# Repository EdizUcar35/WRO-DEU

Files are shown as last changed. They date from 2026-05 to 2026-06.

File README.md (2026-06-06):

# CENGOT — WRO 2026 Future Engineers

This repository contains the engineering materials for Team CENGOT's WRO 2026 entry. The project structure follows the WRO engineering-materials template and provides placeholders and guidance for the files required by the competition.

# Table of contents

- Project overview
- Repository structure
- Hardware & BOM (placeholder)
- Schematics and wiring
- 3D models and mechanical parts
- Software (control code)
- Media (photos & video)

---

# Project overview

CENGOT Robot is an autonomous small-scale vehicle developed for the WRO 2026 Future Engineers track. The platform is designed to compete in both the Open and Obstacle challenge modules by combining reliable low-level control, on-board perception, and modular mechanical design. The system emphasizes reproducibility, easy repair (3D-printable parts), and clear documentation so judges and developers can reproduce the build and test results.

## Objectives
- Reliable line-following on printed tracks with robust recovery when the line is lost.
- Color-based and distance-based obstacle detection with safe avoidance behaviours.
- Modular, printable mechanical parts for quick iteration and repair.
- Well-documented build instructions, wiring diagrams, and reproducible software deployment steps.

## System architecture
- High-level processing: Raspberry Pi (Zero 2 W or 4) running Python/OpenCV for camera-based perception, mission planning and telemetry.
- Low-level control: ESP32 for real-time motor and servo control, sensor polling, and encoder counting.
- Sensors: 
- Actuators: Two DC gear motors with encoders driven by an H-bridge motor driver; servo for steering.

## Software overview
- Perception: OpenCV-based color segmentation and contour analysis for obstacle detection.
- Control:
- Utilities: calibration scripts (camera, sensors), data-logging and replay tools, and automated upload scripts for microcontroller firmware.

## Performance targets
- Line-following accuracy: maintain center within ±2 cm at typical test speeds.
- Obstacle detection: reliably detect colored obstacles at ≥0.5 m in normal indoor lighting.
- End-to-end demo runtime: at least 3 minutes running on the chosen battery (depends on battery capacity and motor load).

## Repository deliverables
- Mechanical files and printable parts: `models/`
- Wiring diagrams and schematics: `schemes/`
- Source code and sketches: `src/`
- Team and vehicle photos: `t-photos/`, `v-photos/`
- Demonstration videos and links: `video/`

## Members:

Artun Andaç (Team Leader)

- Freshman, Dokuz Eylül University.
- Role:
- Contact: artunandac0@gmail.com

Ediz Uçar

- Freshman, Dokuz Eylül University
- Role:
- Contact: ucar.ediz35@gmail.com

Can Özdemir

- Freshman, Dokuz Eylül University
- Role:
- Contact: canozdemir8084@gmail.com

Coach:

Hakan Akduman

- Senior, Dokuz Eylül University
- Contact: hakanakduman2002@gmail.com

---

# Repository structure

| Directory | Purpose / Contents |
|---|---|
| [models/](models/) | 3D-printable parts and CAD files (3MF, STL, STEP) with assembly notes and print settings |
| [schemes/](schemes/) | Circuit diagrams, wiring lists and schematics (PNG, JPG, PDF) |
| [src/](src/) | Source code: Arduino sketches, Python scripts, utilities, and build/upload instructions |
| [other/](other/) | Additional documentation: datasheets, communication protocols, SBC setup notes, datasets, troubleshooting |
| [t-photos/](t-photos/) | Team photos (official and casual) with captions and names |
| [v-photos/](v-photos/) | Vehicle photos covering multiple views (front, back, left, right, top, bottom) |
| [video/](video/) | Demonstration videos and `video.md` with links and timestamps |

---

# Hardware 

Add links to datasheets and pinouts in `schemes/`.

---

| Used in | Name | Photo | Description | Quantity |
|---|---|---|---|---|
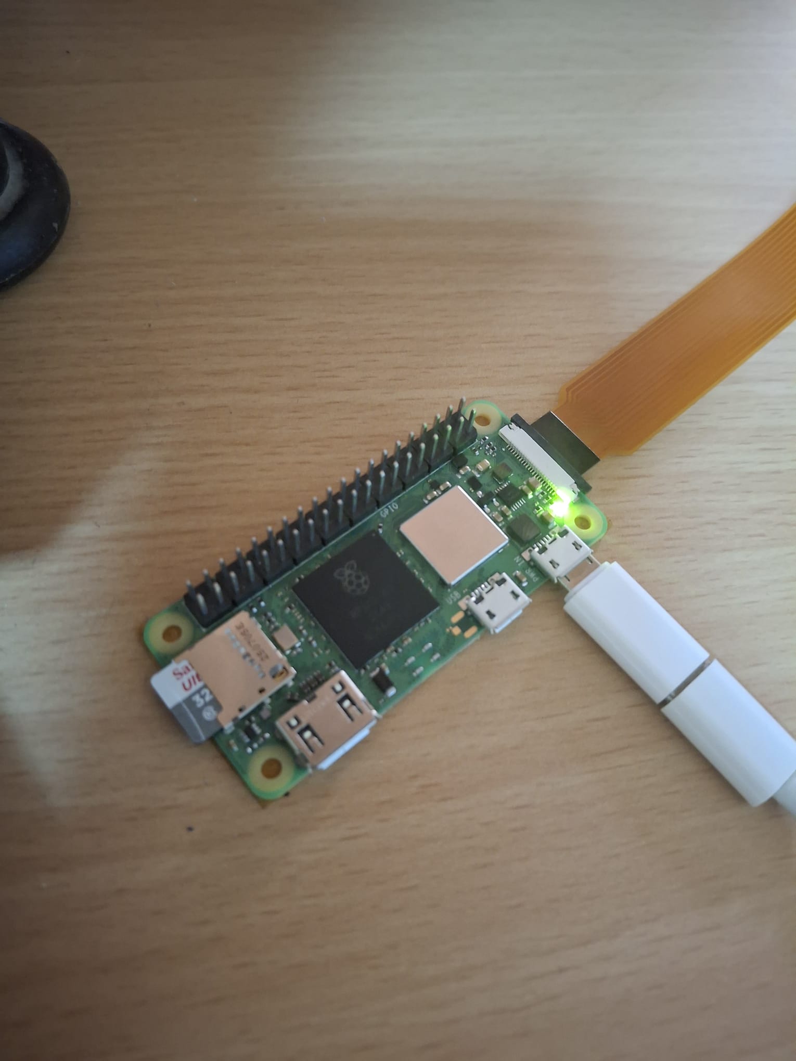
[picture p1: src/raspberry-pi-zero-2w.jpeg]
| Obstacle detecting | Raspberry Pi Zero 2 W |  | Main onboard computer that runs the Python vision software and processes camera frames with OpenCV. | 1 |
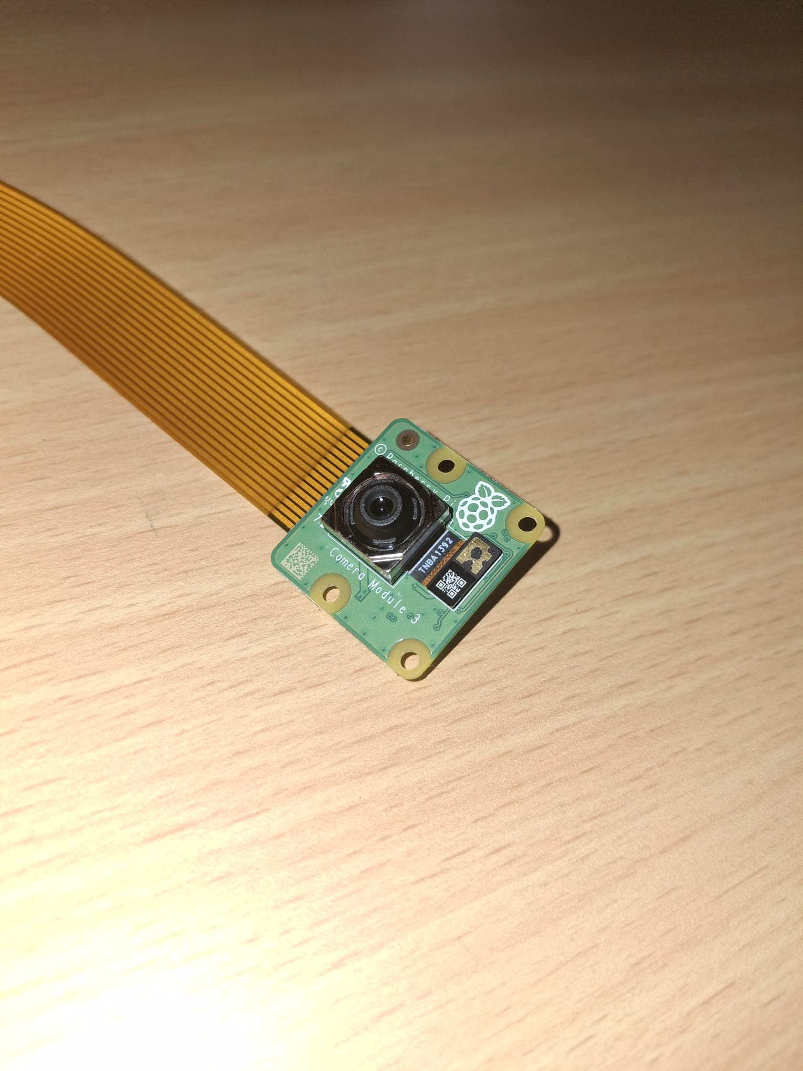
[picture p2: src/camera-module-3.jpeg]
| Obstacle detecting | Raspberry Pi Camera Module 3 |  | Camera module that captures the live image stream used to detect the red and green obstacle signs on the track. | 1 |
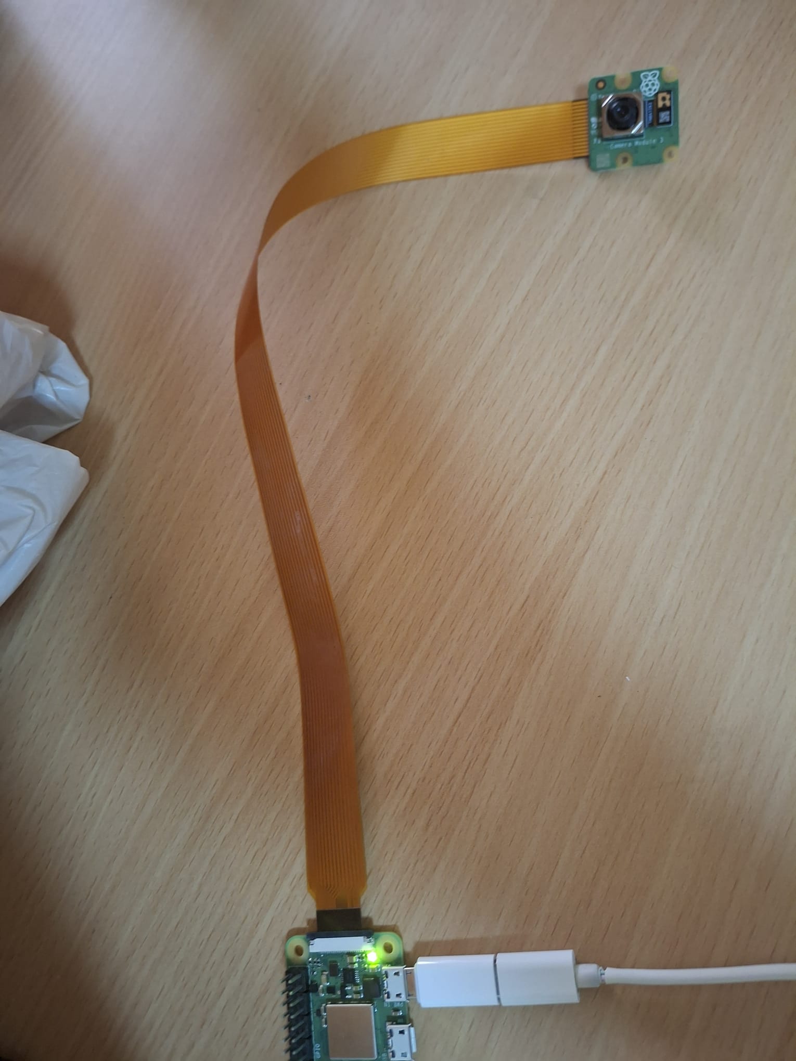
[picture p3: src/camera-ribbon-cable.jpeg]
| Obstacle detecting | Raspberry Pi Camera Ribbon Cable |  | Flexible cable that connects the camera module to the Raspberry Pi and transfers image data for processing. | 1 |

---

# Schematics and wiring

The object-detecting schematic below shows the camera-based vision setup used in the obstacle module. In the project, this scheme is the link between image capture and obstacle decisions: the camera collects the scene, the Raspberry Pi processes it, and the result is used by the robot's driving logic.

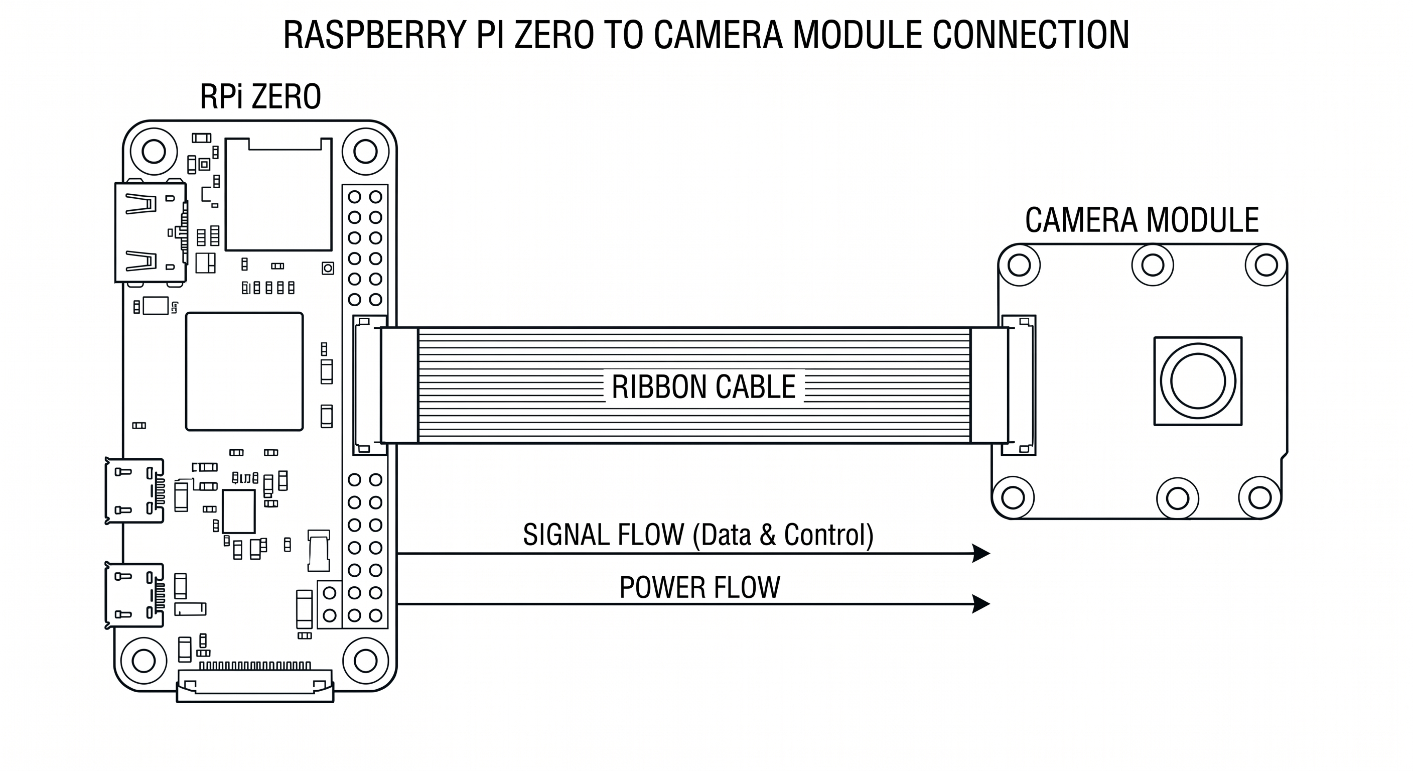
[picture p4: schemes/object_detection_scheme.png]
Object detecting scheme


Store all other schematic files in `schemes/` and keep them captioned clearly so the purpose of each diagram is easy to understand.

---

# 3D models and mechanical parts

- `models/new_design/` — the competition-ready redesign. This is the current, production-ready collection used for the final build.
- `models/old_design/` — archived iterations and legacy variants kept for reference and troubleshooting.

## Why this folder matters
- Fully original: the chassis, wheel hubs, axles, motor mounts, Ackerman steering linkage, servo tower, camera mount (base/head/body), and power-transfer components were modeled from scratch for this project. No third-party CAD parts were imported — every printable geometry was created or adapted by the team to meet packaging, strength and assembly constraints.
- Ready-to-print: parts are exported as 3MF/STL and accompanied by preview images so you can quickly validate orientation and look before printing.

## Quick visual tour
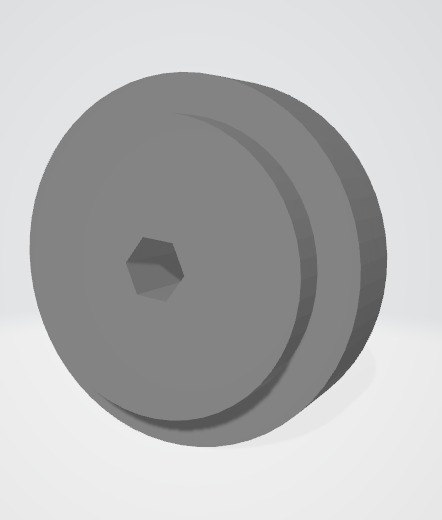
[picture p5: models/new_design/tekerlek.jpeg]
wheel preview
- Wheel system:  — compact, printable, and tuned for a cleaner press-fit than the early versions.
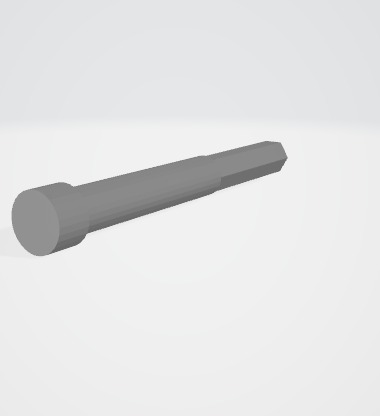
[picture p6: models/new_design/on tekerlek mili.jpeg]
front axle preview
- Front axle path:  — simplified geometry that reduces play and makes alignment easier.
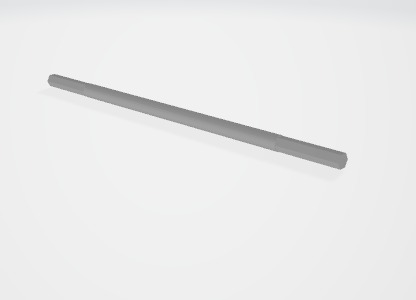
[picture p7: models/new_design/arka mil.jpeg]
rear transfer preview
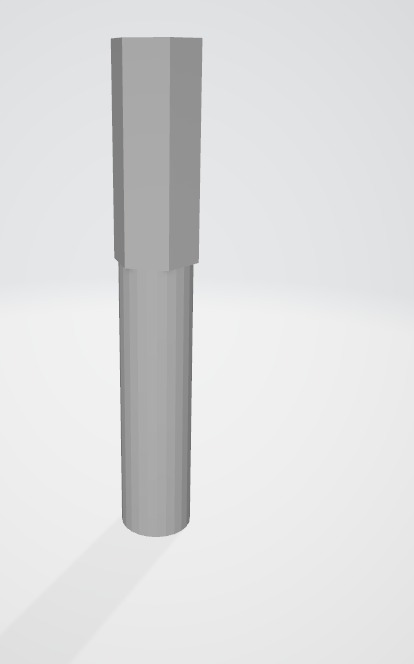
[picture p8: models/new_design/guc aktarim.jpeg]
power transfer preview
- Rear axle and drive transfer:  and  — built to keep the drivetrain stable and the load path predictable.
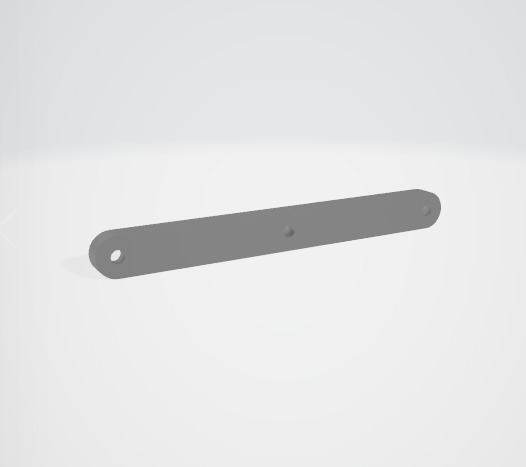
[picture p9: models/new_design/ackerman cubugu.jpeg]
Ackerman preview
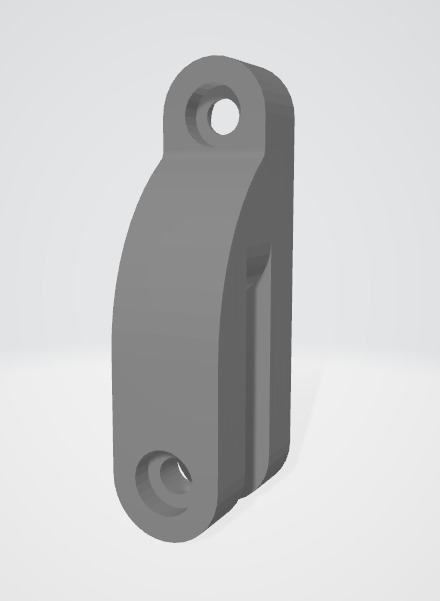
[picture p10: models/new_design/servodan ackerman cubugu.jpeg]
servo linkage preview
- Steering linkage:  and  — refined so the steering response is smoother and the geometry is easier to tune.
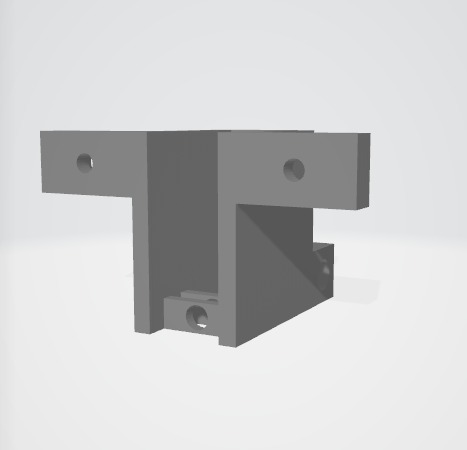
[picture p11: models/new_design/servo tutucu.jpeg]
servo tower preview
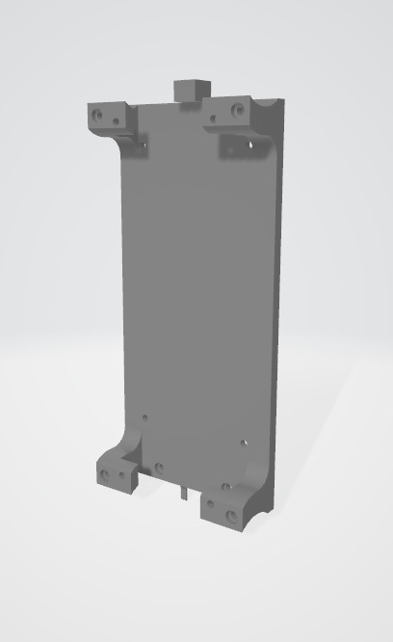
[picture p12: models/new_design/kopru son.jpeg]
bridge end preview
- Servo tower and top support:  and  — designed to stiffen the front assembly and reduce flex.
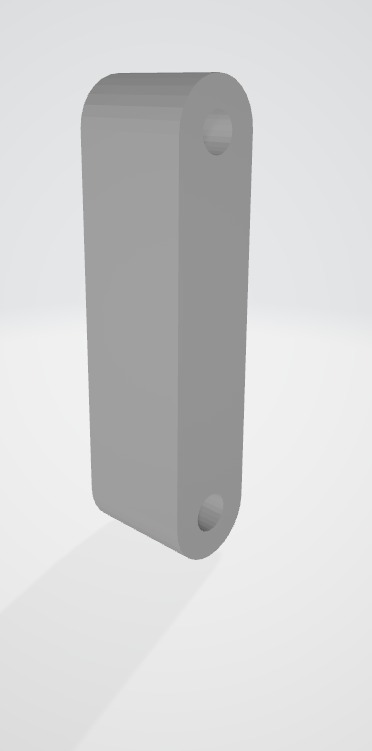
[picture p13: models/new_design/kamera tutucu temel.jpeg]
camera base preview
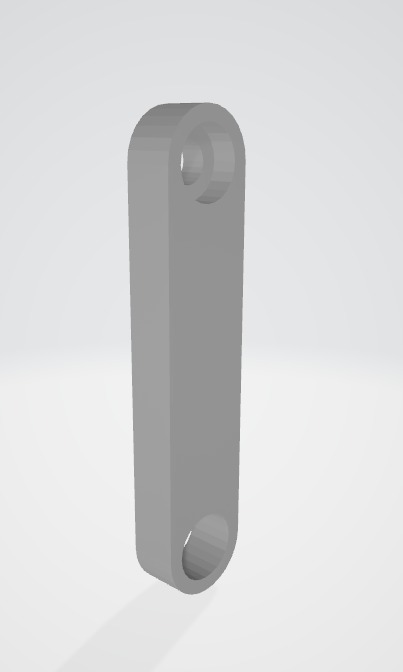
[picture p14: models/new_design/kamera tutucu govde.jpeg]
camera body preview
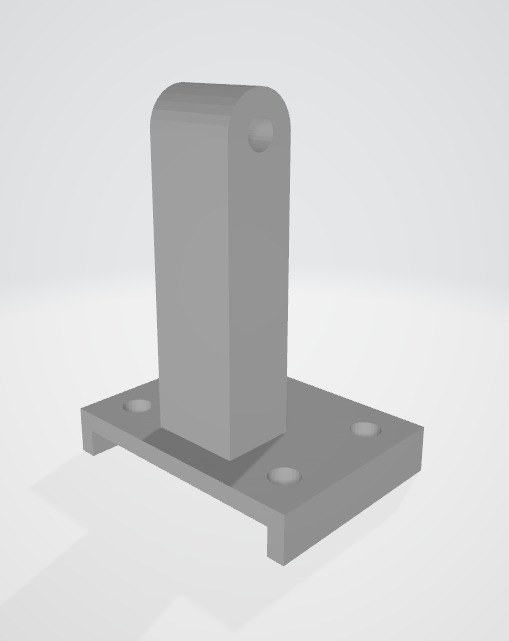
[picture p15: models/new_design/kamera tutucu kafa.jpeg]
camera head preview
- Camera module: , , and  — split into separate pieces so the camera angle can be adjusted without rebuilding the mount.
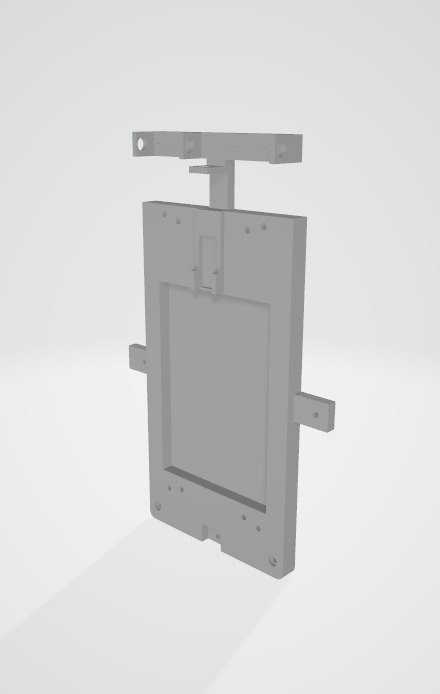
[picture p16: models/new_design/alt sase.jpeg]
chassis preview
- Chassis base:  — cleaner structure, simpler mounting points, and more practical access to electronics than the earlier body shells.

## Old design vs new design

| Area | Old design | New design | Improvement |
|---|---|---|---|
| Chassis | Larger, more fragmented body parts with more experimental geometry | Cleaner base structure with more deliberate mounting areas | Better access, easier assembly, and less wasted print time |
| Steering | More iterations and loose linkage experiments | Refined Ackerman geometry and clearer servo connection path | Smoother steering and more predictable turn behavior |
| Axles / drivetrain | Multiple legacy axle variants used for testing | More compact axle and transfer layout | Reduced complexity and better mechanical consistency |
| Camera mount | Earlier mounts were more rigid and less adjustable | Split camera mount with base, body, and head sections | Easier angle tuning and faster replacement if a part breaks |
| Wheel parts | Several prototype wheel revisions | Final wheel geometry tuned for fit and printability | Better press-fit behavior and cleaner assembly |
| Overall packaging | More trial-and-error and bulkier assemblies | More compact, purpose-built layout | Less clutter, faster service, and a more competition-ready build |

## What changed in practice
- The new design is not just a visual cleanup; it is a structural improvement. Parts were simplified where possible, reinforced where needed, and split into assemblies that are easier to print and replace.
- The final model makes better use of print volume and reduces the amount of post-processing needed before assembly.
- The geometry was reworked to make the robot easier to service during competition, especially around steering, camera alignment, and drivetrain access.

## Assembly highlights
- Fasteners: mostly M3 screws; use M2.5 where space is limited. Use washers and threadlock for high-vibration locations.
- Orientation & supports: many parts were designed to be printed upright to preserve bore integrity — check preview images in each subfolder for recommended orientation.

## Design provenance and license
- All `models/new_design/` parts are original to this project and intended for reproduction by teams and judges.
- Licensing: see [models/LICENSE](models/LICENSE) for terms; per-file notes and preview images live in the corresponding subfolders (see `models/README.md`).

---

## Software (src)

The `src/` folder contains the working software for the robot, plus one short guide that explains how to run it. The code is intentionally split into three parts so each layer can be checked and improved separately before everything is combined.

The Arduino side is made of two control sketches: [src/28_Mayis_Kontrol_Kodu_old.ino](src/28_Mayis_Kontrol_Kodu_old.ino) and [src/28_Mayis_Kontrol_Kodu_new.ino](src/28_Mayis_Kontrol_Kodu_new.ino). The old sketch is a quick hardware check, while the new sketch is the main robot-control version that reads sensors, sends data to the Raspberry Pi, and accepts basic steering and motor commands.

The vision side is handled by [src/obstacle_detector.py](src/obstacle_detector.py). This script uses the Raspberry Pi camera to detect red and green obstacle signs and convert what it sees into a simple driving decision. It looks only at the useful part of the image, filters the colors, removes noise, finds the strongest obstacle candidate, and reports the result in a form the robot can use. This makes it a compact module that can be tested alone before being connected to the rest of the control system.

```python
roi_frame, offset_x, offset_y = get_region_of_interest(corrected_frame)
hsv_frame = cv2.cvtColor(roi_frame, cv2.COLOR_RGB2HSV)

for color_name, hsv_ranges in COLOR_RANGES.items():
	mask = create_color_mask(hsv_frame, hsv_ranges)
	obstacle = find_largest_obstacle(mask, color_name, offset_x, offset_y)
```

```python
if obstacle_color == "red":
	steering_command = "steer_left"
elif obstacle_color == "green":
	steering_command = "steer_right"
else:
	steering_command = "go_straight"
```

The most useful parts of the obstacle-detection logic are the ones that make the camera output more stable and easier to trust on the track. First, the script does not analyze the whole frame; it focuses on a smaller region where the obstacle is expected to appear. That simple move reduces background distractions and makes the robot react to the sign that actually matters in front of it. Then the image is handled in HSV color space instead of raw camera colors, because HSV is much more forgiving when lighting changes. This is especially helpful in an indoor competition environment where shadows, reflections, and brightness shifts can confuse a plain RGB-based detector.

```python
ROI_TOP_RATIO = 0.25
ROI_BOTTOM_RATIO = 0.95
ROI_LEFT_RATIO = 0.10
ROI_RIGHT_RATIO = 0.90

COLOR_RANGES = {
	"red": [((0, 70, 50), (12, 255, 255)), ((165, 70, 50), (180, 255, 255))],
	"green": [((40, 60, 50), (88, 255, 255))]
}
```

The color matching itself is also tuned in a practical way. Red is treated with two separate hue ranges so the script can catch both ends of the red spectrum, while green has its own defined range. After that, the detector uses mask cleanup steps to remove tiny noisy spots and close small gaps inside the detected shapes. That means the robot is less likely to react to random pixels, small reflections, or partial detections. Once the cleaned mask is ready, the script looks for contours and keeps the largest valid one as the main obstacle. In simple terms, the system assumes the biggest matched object is the one the robot should care about most.

```python
kernel = np.ones((5, 5), np.uint8)
total_mask = cv2.morphologyEx(total_mask, cv2.MORPH_OPEN, kernel)
total_mask = cv2.morphologyEx(total_mask, cv2.MORPH_CLOSE, kernel)

largest_contour = max(contours, key=cv2.contourArea)
contour_area = cv2.contourArea(largest_contour)
```

Finally, the obstacle position is interpreted relative to the center of the frame, with a small dead zone so the robot does not overreact to tiny shifts. The output becomes a very direct driving choice: red leads to a left steering response, green leads to a right steering response, and no valid obstacle means the robot keeps moving normally. This is the part that makes the module useful in practice, because it turns camera data into a decision the robot can actually follow.

```python
if obstacle_center_x < frame_center_x - CENTER_DEAD_ZONE:
	return "left"
if obstacle_center_x > frame_center_x + CENTER_DEAD_ZONE:
	return "right"
return "center"
```

## Evolution of `obstacle_detecting`
- This module did not start as a dedicated obstacle detector. Earlier, the idea was closer to a general `color_detecting` script that tried to identify colors in the camera image.
- Over time, the project moved away from broad color recognition and toward a task-based obstacle module. That is why the script was renamed and reorganized into `obstacle_detecting`.
- The newer version is more practical for competition use: it focuses on only the colors that matter, uses a tighter image region, filters out noise, and turns the visual result into an actual driving choice.
- In other words, the change was not just cosmetic. The script evolved from a broad experimental detector into a focused obstacle-handling tool that matches the game rules better.

To run the software in practice, upload the Arduino sketch that matches the current hardware setup, then start the Python obstacle detector on the Raspberry Pi.

---

# Media (team & vehicle photos, videos)

- `t-photos/` — add an official team photo and one casual team photo. Include a caption and names in a small `t-photos/README.md` file.
- `v-photos/` — photos of the assembled robot: front, back, left, right, top, bottom. Include orientation notes and scale references.
- `video/video.md` — include links to demonstration videos (YouTube or raw files) and a short timestamped description of what the video shows.

Example `video/video.md` content:

```
Driving demonstration — https://youtu.be/your_video_id — shows line-following and obstacle avoidance.
```

---

# License

- **Code & scripts:** MIT License — see `LICENSE` for the full text.
- **3D models & mechanical designs (models/):** Creative Commons Attribution-ShareAlike 4.0 — see `models/LICENSE` for details.

---

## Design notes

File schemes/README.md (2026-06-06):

Electromechanical diagrams
====

This directory must contain one or several schematic diagrams in form of JPEG, PNG or PDF of the electromechanical components illustrating all the elements (electronic components and motors) used in the vehicle and how they connect to each other.

## Object detection scheme

Object detection scheme

This diagram shows the camera-based obstacle-detection setup used in the project. The Raspberry Pi Zero 2 W receives the image stream from the Raspberry Pi Camera Module 3 through the ribbon cable, processes the frame, and uses the result to support the robot's obstacle-handling logic.

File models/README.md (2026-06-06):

Models
===

This section of the project provides a short description of each model's purpose, a link to the printable 3D model file, and a link to the corresponding photo to help identify parts quickly.

| Photo | Model name | Model file | Function / Description |
|---|---|---|---|
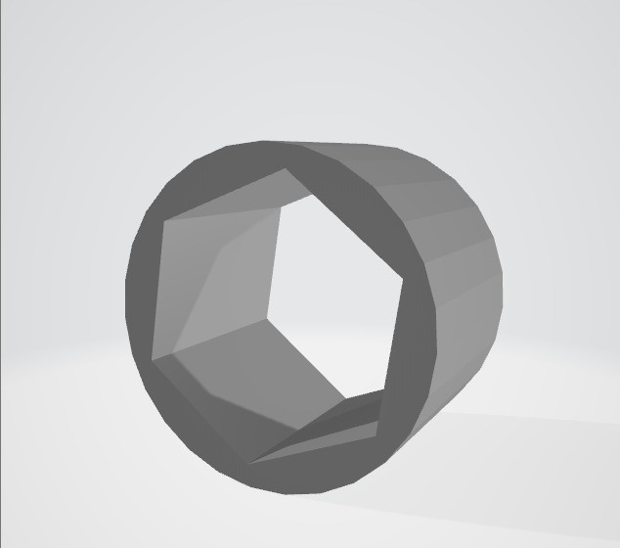
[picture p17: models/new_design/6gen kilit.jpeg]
6 Gen Kilit
|  | 6 Gen lock | [Wro Ana Şase_Wro Ana Şase_6 Gen Kilit.3mf](./new_design/Wro%20Ana%20%C5%9Ease_Wro%20Ana%20%C5%9Ease_6%20Gen%20Kilit.3mf) | A small locking component used to secure assemblies or gears in place; provides a simple physical latch to prevent undesired rotation or disassembly. |
| Ackerman Çubuğu |  (Ackerman rod) | [Wro Ana Şase_Wro Ana Şase_Ackerman Çubuğu.3mf](./new_design/Wro%20Ana%20%C5%9Ease_Wro%20Ana%20%C5%9Ease_Ackerman%20%C3%87ubu%C4%9Fu.3mf) | Steering linkage implementing Ackerman geometry; translates servo motion into coordinated steering of the front wheels. |
| Alt Şase |  (Lower chassis) | [Wro Ana Şase_Wro Ana Şase_Alt Şase.3mf](./new_design/Wro%20Ana%20%C5%9Ease_Wro%20Ana%20%C5%9Ease_Alt%20%C5%9Ease.3mf) | The lower chassis plate that forms the base of the vehicle; provides mounting points for motors, axles, and electronics. |
| Arka Güç Aktarım |  (Rear power transmission) | [Wro Ana Şase_Wro Ana Şase_Arka Güç Aktarım.3mf](./new_design/Wro%20Ana%20%C5%9Ease_Wro%20Ana%20%C5%9Ease_Arka%20G%C3%BC%C3%A7%20Aktar%C4%B1m.3mf) | Gear or coupling assembly that transmits torque from the motor to the rear axle; critical for drivetrain power transfer. |
| Arka Mil |  (Rear axle) | [Wro Ana Şase_Wro Ana Şase_Arka Mil.3mf](./new_design/Wro%20Ana%20%C5%9Ease_Wro%20Ana%20%C5%9Ease_Arka%20Mil.3mf) | The rear axle shaft that carries the rear wheels and transfers rotational motion from the drivetrain to the wheels. |
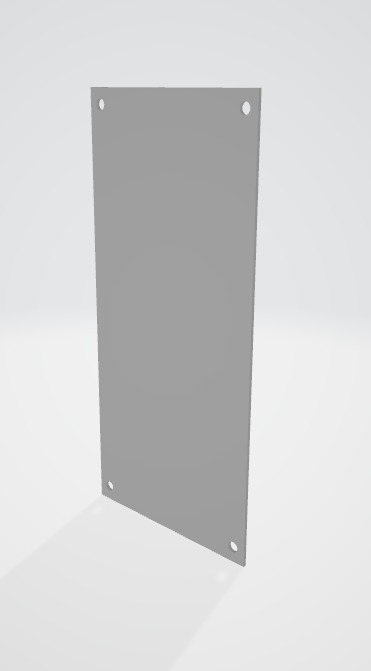
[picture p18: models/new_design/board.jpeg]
Board
|  |  (electronic board placeholder) | [Wro Ana Şase_Wro Ana Şase_Board Basılmayacak.3mf](./new_design/Wro%20Ana%20%C5%9Ease_Wro%20Ana%20%C5%9Ease_Board%20Bas%C4%B1lmayacak.3mf) | A placeholder or mounting plate intended to show where the electronics board is positioned; labeled as not-for-print in the filename. |
| Kamera Tutucu Gövde | (Camera mount body) | [Wro Ana Şase_Wro Ana Şase_Kamera Tutucu Gövde.3mf](./new_design/Wro%20Ana%20%C5%9Ease_Wro%20Ana%20%C5%9Ease_Kamera%20Tutucu%20G%C3%B6vde.3mf) | Main body component of the camera mount that provides structural support and attachment points for head and base. |
| Kamera Tutucu Kafa | (Camera head) | [Wro Ana Şase_Wro Ana Şase_Kamera Tutucu Kafa .3mf](./new_design/Wro%20Ana%20%C5%9Ease_Wro%20Ana%20%C5%9Ease_Kamera%20Tutucu%20Kafa%20.3mf) | The articulated head piece that allows the camera to be angled or tilted for different viewing orientations. |
| Kamera Tutucu Temel | (Camera mount base) | [Wro Ana Şase_Wro Ana Şase_Kamera Tutucu Temel.3mf](./new_design/Wro%20Ana%20%C5%9Ease_Wro%20Ana%20%C5%9Ease_Kamera%20Tutucu%20Temel.3mf) | Base plate for the camera mount that secures the camera assembly to the chassis. |
| Köprü Son | (Bridge end) | [Wro Ana Şase_Wro Ana Şase_Köprü Son.3mf](./new_design/Wro%20Ana%20%C5%9Ease_Wro%20Ana%20%C5%9Ease_K%C3%B6pr%C3%BC%20Son.3mf) | Structural connector or end-piece used to join sections of the chassis or reinforce spans between components. |
| Ön Tekerlek Mili | (Front wheel axle) | [Wro Ana Şase_Wro Ana Şase_Ön Tekerlek Mili.3mf](./new_design/Wro%20Ana%20%C5%9Ease_Wro%20Ana%20%C5%9Ease_%C3%96n%20Tekerlek%20Mili.3mf) | Front wheel axle that supports the front wheels and links to steering components. |
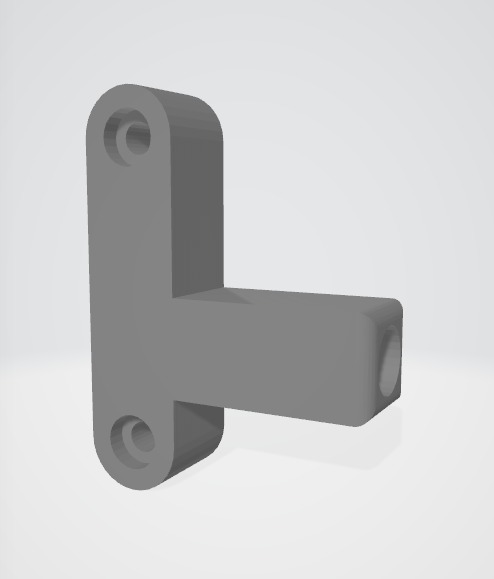
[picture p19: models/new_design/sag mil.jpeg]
Sağ Mil
|  | (Right shaft) | [Wro Ana Şase_Wro Ana Şase_Sağ Mil.3mf](./new_design/Wro%20Ana%20%C5%9Ease_Wro%20Ana%20%C5%9Ease_Sa%C4%9F%20Mil.3mf) | Right-side shaft used for mounting wheels or drivetrain components; matches the left-side counterpart. |
| Servo Tutucu Kule | (Servo holder tower) | [Wro Ana Şase_Wro Ana Şase_Servo Tutucu Kule.3mf](./new_design/Wro%20Ana%20%C5%9Ease_Wro%20Ana%20%C5%9Ease_Servo%20Tutucu%20Kule.3mf) | Tower structure designed to hold a servo securely above the chassis for steering or actuation. |
| Servodan Ackerman Çubuğu | (Servo-to-Ackerman rod) | [Wro Ana Şase_Wro Ana Şase_Servodan Ackerman Çubuğu.3mf](./new_design/Wro%20Ana%20%C5%9Ease_Wro%20Ana%20%C5%9Ease_Servodan%20Ackerman%20%C3%87ubu%C4%9Fu.3mf) | Short linkage that connects the servo output horn to the Ackerman steering rod, enabling responsive steering control. |
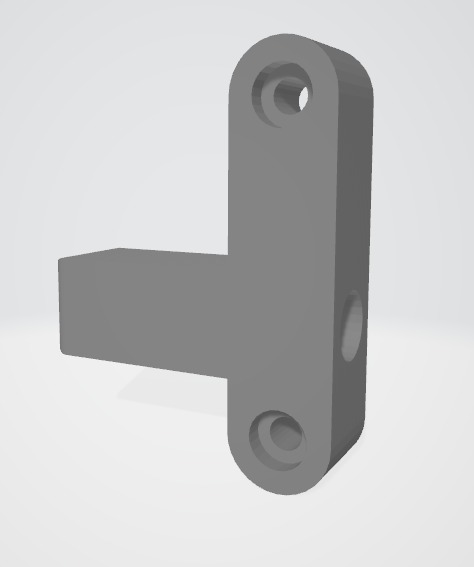
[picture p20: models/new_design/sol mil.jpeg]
Sol Mil
|  | (Left shaft) | [Wro Ana Şase_Wro Ana Şase_Sol Mil.3mf](./new_design/Wro%20Ana%20%C5%9Ease_Wro%20Ana%20%C5%9Ease_Sol%20Mil.3mf) | Left-side shaft counterpart to the right shaft; supports wheel or drivetrain mounting on the left side. |
| Tekerlek | (Wheel) | [Wro Ana Şase_Wro Ana Şase_Tekerlek.3mf](./new_design/Wro%20Ana%20%C5%9Ease_Wro%20Ana%20%C5%9Ease_Tekerlek.3mf) | Standard wheel design for the vehicle; intended to be mounted on the front or rear axles depending on fit. |

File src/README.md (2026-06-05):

Control software
====

## Obstacle Detecting

The obstacle detecting module is used to identify red and green traffic signs on the track by using the Raspberry Pi Camera Module 3 and OpenCV. In the obstacle round, the vehicle must react to colored traffic signs: the red traffic sign represents the right side of the lane, while the green traffic sign represents the left side. Therefore, the software converts the detected color into a basic steering decision for the autonomous vehicle.

The camera is initialized with `Picamera2` at a resolution of `320x240`. This resolution is preferred because it is lightweight enough for the Raspberry Pi Zero 2 W and still provides enough visual information for color-based obstacle detection.

```python
camera_config = camera.create_preview_configuration(
    main={"size": (320, 240), "format": "RGB888"}
)
```

The software only processes the lower-middle part of the image by using a Region of Interest. This reduces false detections from background objects and allows the vehicle to focus on the area where obstacles are expected to appear.

```python
ROI_TOP_RATIO = 0.25
ROI_BOTTOM_RATIO = 0.95
ROI_LEFT_RATIO = 0.10
ROI_RIGHT_RATIO = 0.90
```

The detection algorithm uses the HSV color space instead of directly using RGB values. HSV makes color filtering more stable under different lighting conditions. In this project, only red and green color ranges are defined because these colors represent the traffic signs used in the obstacle game.

```python
COLOR_RANGES = {
    "red": [
        ((0, 70, 50), (12, 255, 255)),
        ((165, 70, 50), (180, 255, 255))
    ],
    "green": [
        ((40, 60, 50), (88, 255, 255))
    ]
}
```

For each color, the program creates a binary mask with `cv2.inRange()`. White pixels in the mask represent the selected color, while black pixels represent the rest of the image. Morphological opening and closing operations are then applied to remove small noise and make the detected obstacle area cleaner.

```python
mask = cv2.inRange(hsv_frame, lower_array, upper_array)

total_mask = cv2.morphologyEx(total_mask, cv2.MORPH_OPEN, kernel)
total_mask = cv2.morphologyEx(total_mask, cv2.MORPH_CLOSE, kernel)
```

After the mask is created, contours are found with OpenCV. The largest contour is selected as the obstacle candidate. Very small contours are ignored with `MIN_CONTOUR_AREA`, which prevents random pixels or reflections from being accepted as obstacles.

```python
MIN_CONTOUR_AREA = 250

largest_contour = max(contours, key=cv2.contourArea)
contour_area = cv2.contourArea(largest_contour)
```

The program calculates the center position and size of the detected obstacle by using a bounding rectangle. This information is stored in a dictionary that includes the obstacle color, area, center point, width, and height.

```python
obstacle = {
    "color": color_name,
    "area": contour_area,
    "center_x": center_x,
    "center_y": center_y,
    "width": width,
    "height": height
}
```

If more than one obstacle is visible, the software selects the obstacle with the largest visible area as the primary obstacle. This is based on the assumption that the larger object in the camera image is usually closer and more important for the vehicle’s next movement.

```python
primary_obstacle = max(obstacles, key=lambda item: item["area"])
```

Finally, the detected obstacle color is converted into a driving decision. If a red obstacle is detected, the vehicle generates a `steer_left` command. If a green obstacle is detected, the vehicle generates a `steer_right` command. If no obstacle is detected, the vehicle continues with `go_straight`.

```python
if obstacle_color == "red":
    steering_command = "steer_left"
    speed_command = "slow_down"

elif obstacle_color == "green":
    steering_command = "steer_right"
    speed_command = "slow_down"
```

The current version prints the detected obstacle data and generated driving command to the terminal. This makes testing easier before connecting the obstacle detection output to the actual motor and steering control system.

### Hardware Components Used for Color Detecting

| Component | Image | Purpose |
| --- | --- | --- |
| Raspberry Pi Zero 2 W |  | The Raspberry Pi Zero 2 W runs the Python control software and processes the camera frames using OpenCV. It acts as the main onboard computer of the vehicle. |
| Raspberry Pi Camera Module 3 |  | The Camera Module 3 captures real-time images from the environment. These images are used by the color detection algorithm to identify objects or markers in front of the vehicle. |
| Raspberry Pi Camera Ribbon Cable |   | The camera ribbon cable connects the Camera Module 3 to the Raspberry Pi Zero 2 W. It transfers image data from the camera to the Raspberry Pi for processing. |

This module is an important part of the robot car’s control software because it converts visual information into simple color-based data. This detected color can later be connected to the decision-making part of the vehicle, allowing the car to react to colored signs, objects, or track markers.

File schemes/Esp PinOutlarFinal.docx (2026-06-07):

ESP32 S2 Mini Pini | Sürücü / Sensör Etiketi | Bağlantı Amacı ve Detaylı İşlevi
3V3 | VCC / 3.3V | Tüm mantıksal sensörlerin ve ekranın beslemesi.
GND | GND | Parazitleri önlemek için birleşen ortak toprak hattı.
GPIO 1 | Buton 1 | Dijital Giriş (Dahili Pull-Up dirençli).
GPIO 2 | Buton 2 | Dijital Giriş (Dahili Pull-Up dirençli).
GPIO 3 | Sol IR Sensör OUT | Sol şerit kontrolü için dijital giriş.
GPIO 4 | Buton 3 | Dijital Giriş (Dahili Pull-Up dirençli).
GPIO 5 | Orta IR Sensör OUT | Merkez şerit kontrolü için dijital giriş.
GPIO 6 | Buton 4 | Dijital Giriş (Dahili Pull-Up dirençli).
GPIO 7 | Sağ IR Sensör OUT | Sağ şerit kontrolü için dijital giriş.
GPIO 8 | MPU6050 + OLED (SDA) | I2C Ortak Veri Hattı (Sensör ve ekran verileri akar).
GPIO 9 | MPU6050 + OLED (SCL) | I2C Ortak Saat Hattı (Haberleşme ritmini belirler).
GPIO 10 | Buton 5 | Dijital Giriş (Dahili Pull-Up dirençli).
GPIO 11 | DRV8833 - STBY | Sürücü Şalteri. HIGH konumunda sürücü açık, LOW'da uykuda.
GPIO 12 | Direksiyon Servosu Sinyal | Tekerlek yön açısını belirleyen donanımsal PWM hattı.
GPIO 13 | Buton 6 | Dijital Giriş (Dahili Pull-Up dirençli).
GPIO 14 | Buton 7 | Dijital Giriş (Dahili Pull-Up dirençli).
GPIO 15 | BOŞTA | Kesinlikle kullanılmıyor (Dahili Mavi LED hattı).
GPIO 16 | DRV8833 - AIN1 | Motor Yön Belirleme Sinyali 1 (Sadece Dijital High/Low).
GPIO 17 | BOŞTA | Kesinlikle kullanılmıyor (Genel Amaçlı Genel Yedek).
GPIO 18 | BOŞTA | Kesinlikle kullanılmıyor (Genel Amaçlı Genel Yedek).
GPIO 21 | Buton 8 | Dijital Giriş (Dahili Pull-Up dirençli).
GPIO 33 | DRV8833 - AIN2 | Motor Yön Belirleme Sinyali 2 (Sadece Dijital High/Low).
GPIO 34 | Hall Effect Sensör OUT | Manyetik tekerlek tur sayımı için donanımsal Interrupt pini.
GPIO 35 | Buton 9 | Dijital Giriş (Dahili Pull-Up dirençli).
GPIO 36 | Raspberry Pi UART RX | Raspberry Pi'ye veri paketleri yollayan TX hattı.
GPIO 37 | Raspberry Pi UART TX | Raspberry Pi'den komutları alan RX hattı.
GPIO 38 | Buton 10 | Dijital Giriş (Dahili Pull-Up dirençli).
GPIO 40 | DRV8833 - PWMA | Motor Hız Kontrolü Hattı (Donanımsal PWM Çıkışı).
GPIO 39 | BOŞTA | Kesinlikle kullanılmıyor (Genel Amaçlı Genel Yedek).

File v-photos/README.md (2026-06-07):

Vehicle Photos
====

This directory contains the six required vehicle photos. The images are organized by viewing direction so it is easy to verify that every side is covered.

| View | Photo |
| --- | --- |
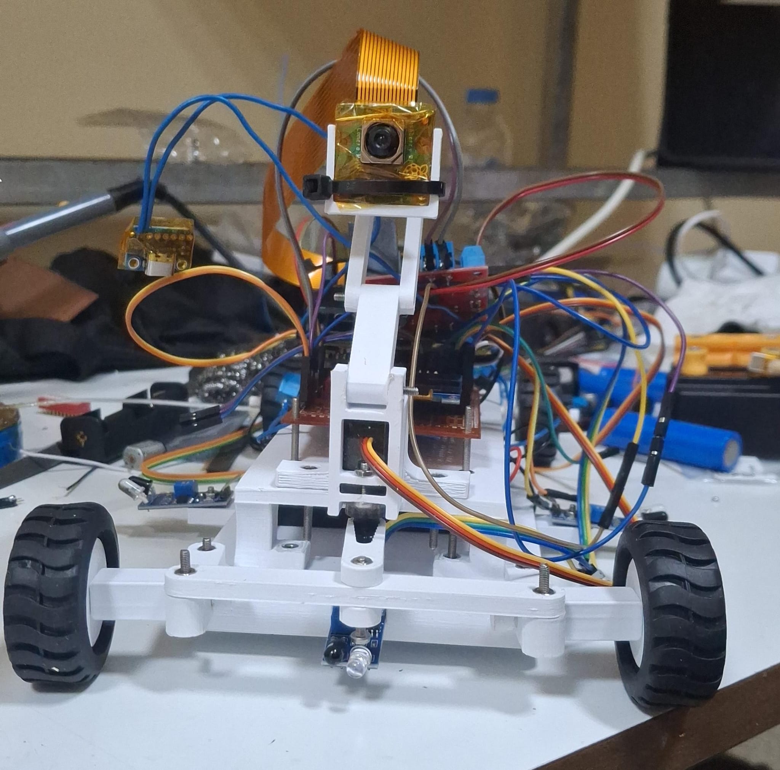
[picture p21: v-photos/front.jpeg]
| Front |  |
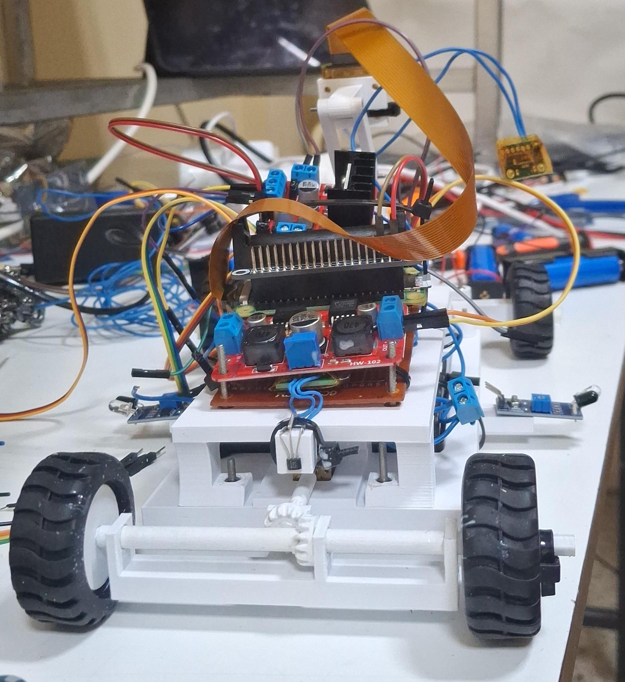
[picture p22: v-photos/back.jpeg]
| Back |  |
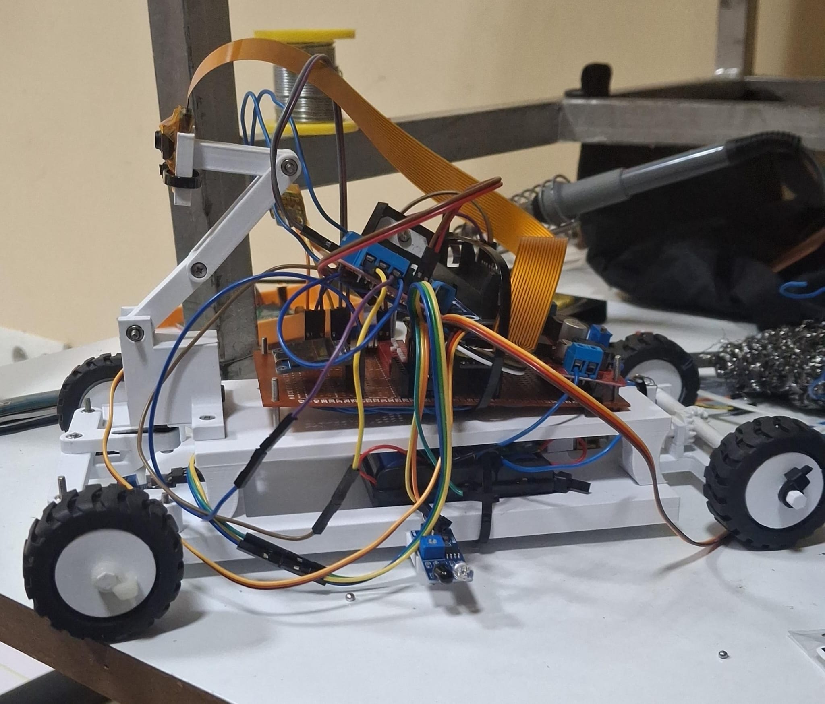
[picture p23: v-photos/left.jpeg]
| Left |  |
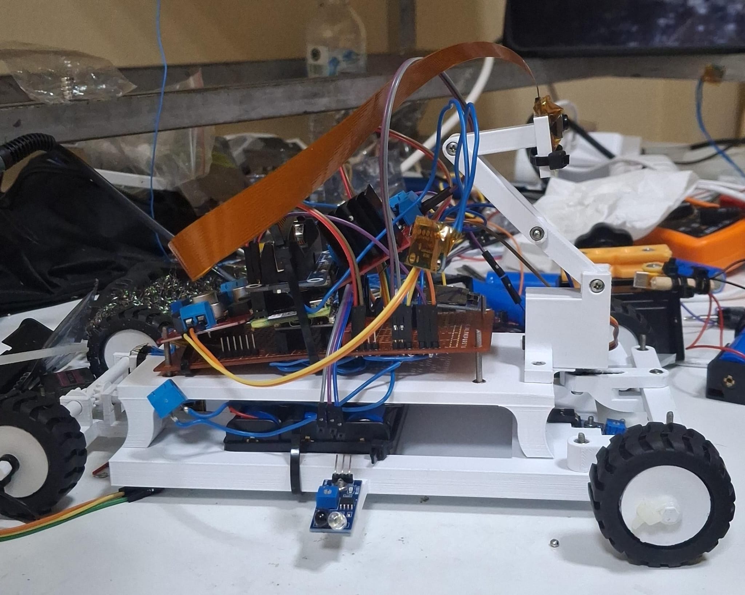
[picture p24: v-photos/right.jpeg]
| Right |  |
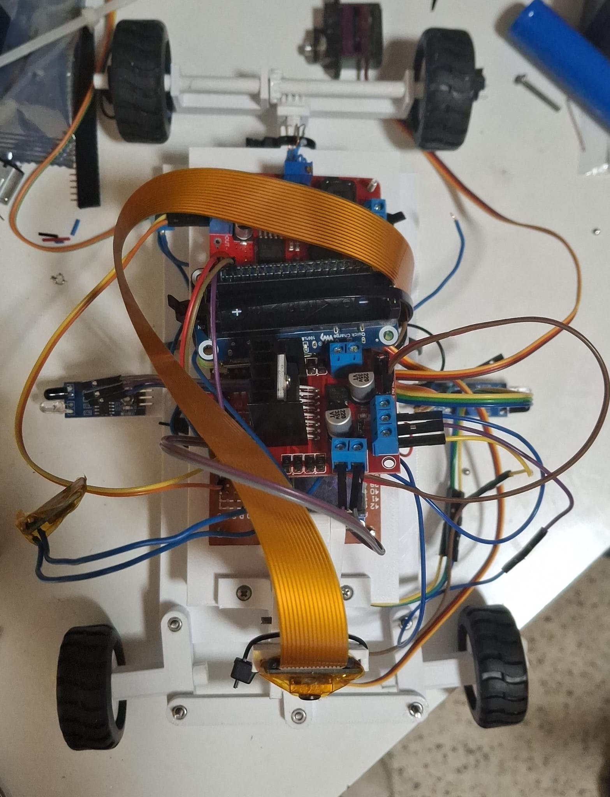
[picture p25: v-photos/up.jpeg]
| Top |  |
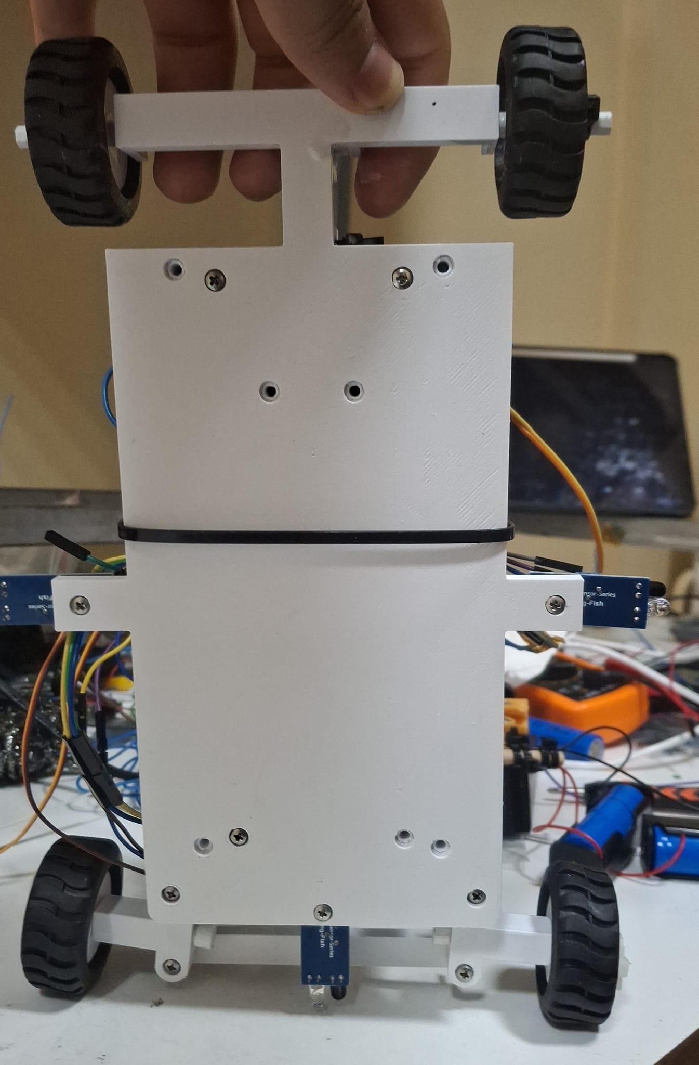
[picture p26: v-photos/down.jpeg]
| Bottom |  |

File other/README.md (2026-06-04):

## Team Logo 

<!-- <img src="team_logo.png" alt="Team Logo" width="300"> -->
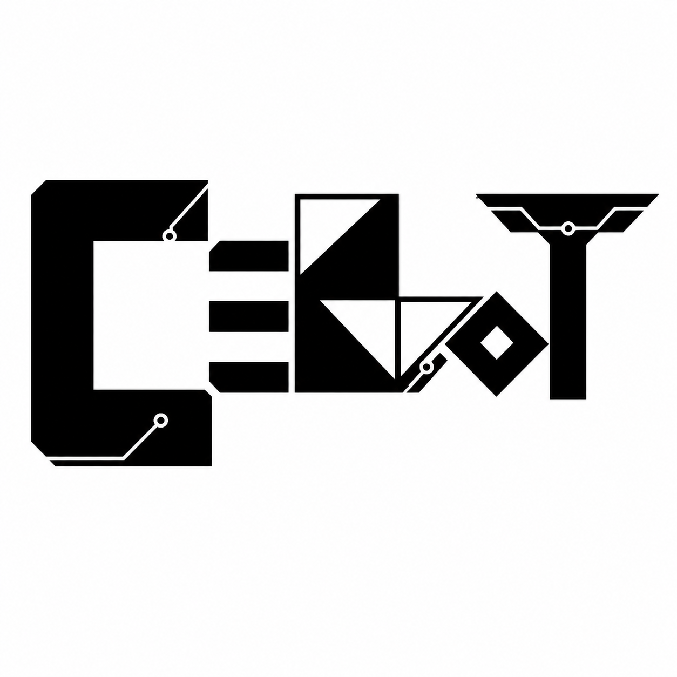
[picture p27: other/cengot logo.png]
CENGOT Logo


---

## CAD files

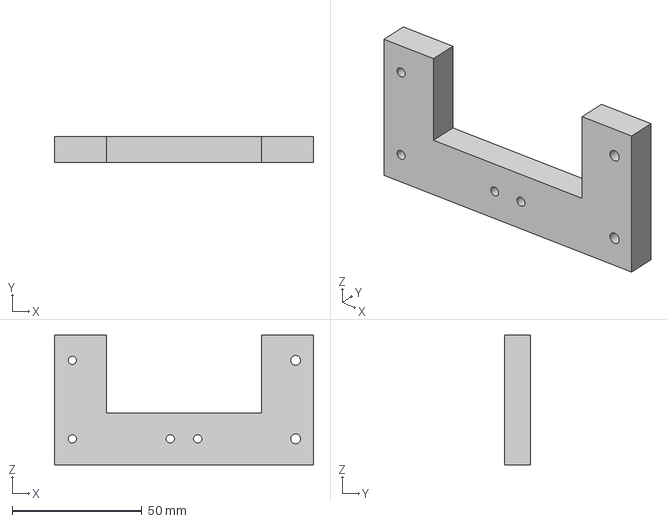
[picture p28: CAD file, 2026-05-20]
models/Alt Gövde Main.3mf
100.0 x 10.0 x 50.0 mm

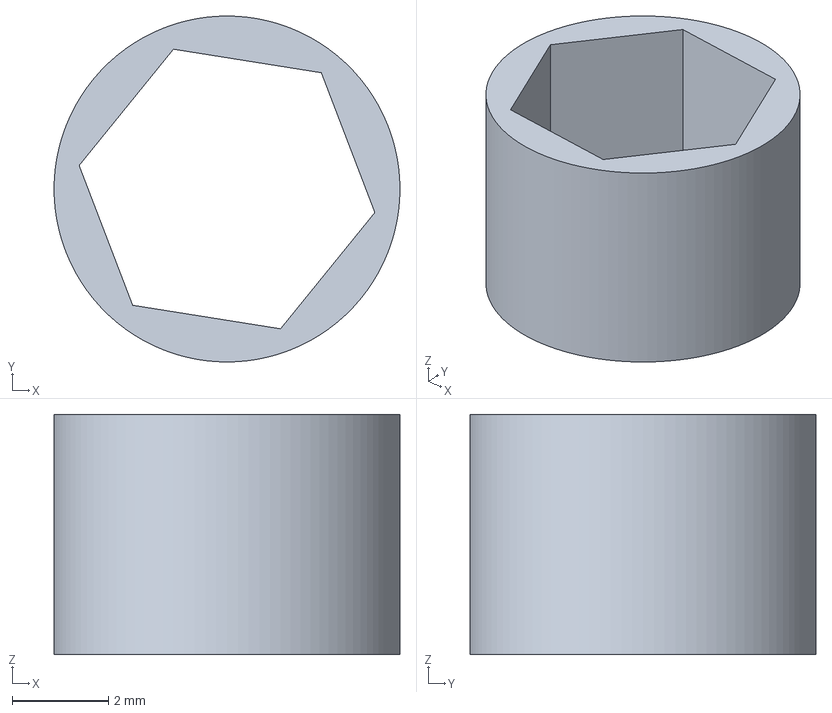
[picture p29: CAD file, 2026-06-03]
models/Mil Sabitleyici V1.0.3mf
7.20 x 7.20 x 5.00 mm

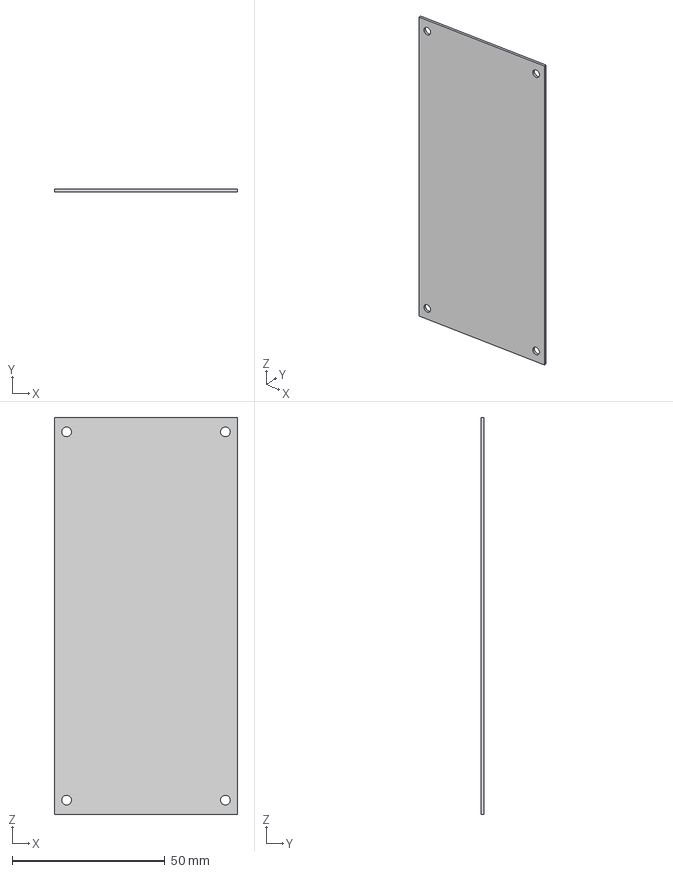
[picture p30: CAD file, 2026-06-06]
models/new_design/Wro Ana Şase_Wro Ana Şase_Board Basılmayacak.3mf
60.0 x 1.00 x 130.0 mm

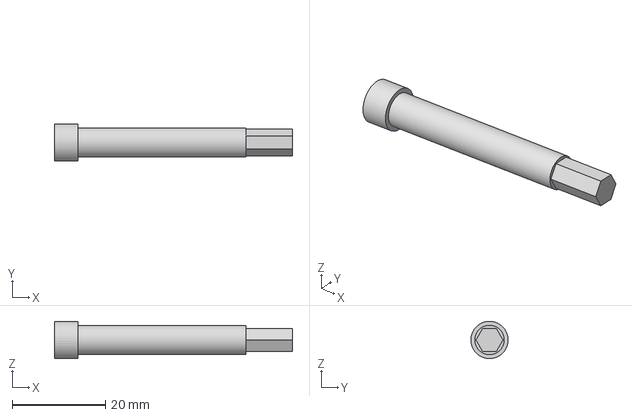
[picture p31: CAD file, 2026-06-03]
models/Ön Tekerlek Mil V1.0.3mf
51.0 x 8.00 x 7.99 mm

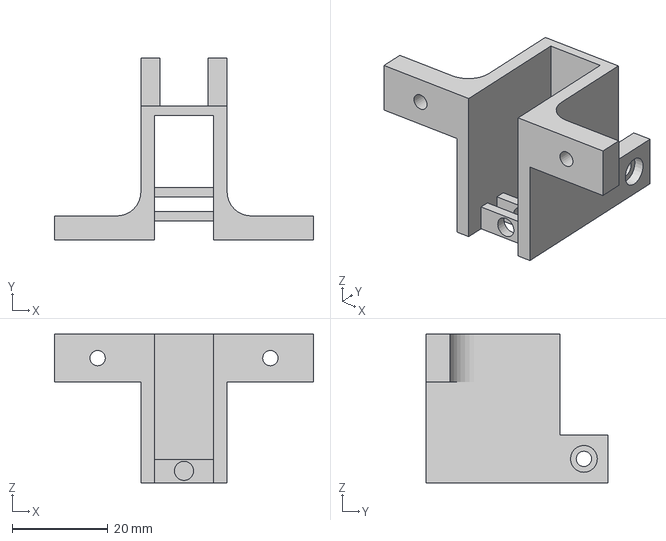
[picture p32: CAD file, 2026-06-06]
models/new_design/Wro Ana Şase_Wro Ana Şase_Servo Tutucu Kule.3mf
54.0 x 37.9 x 31.0 mm

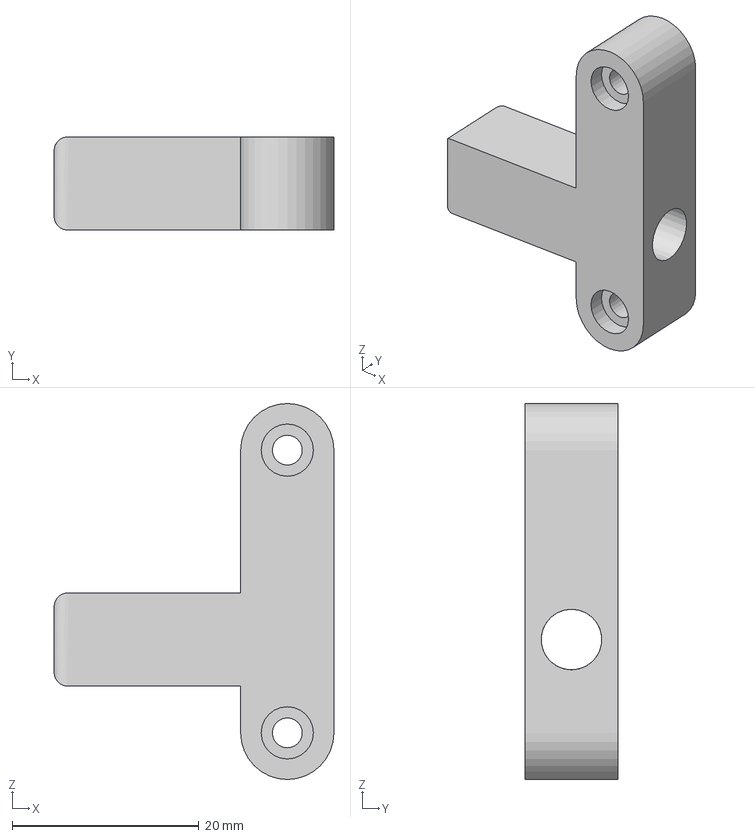
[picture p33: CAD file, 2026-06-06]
models/new_design/Wro Ana Şase_Wro Ana Şase_Sol Mil.3mf
30.0 x 10.0 x 40.3 mm

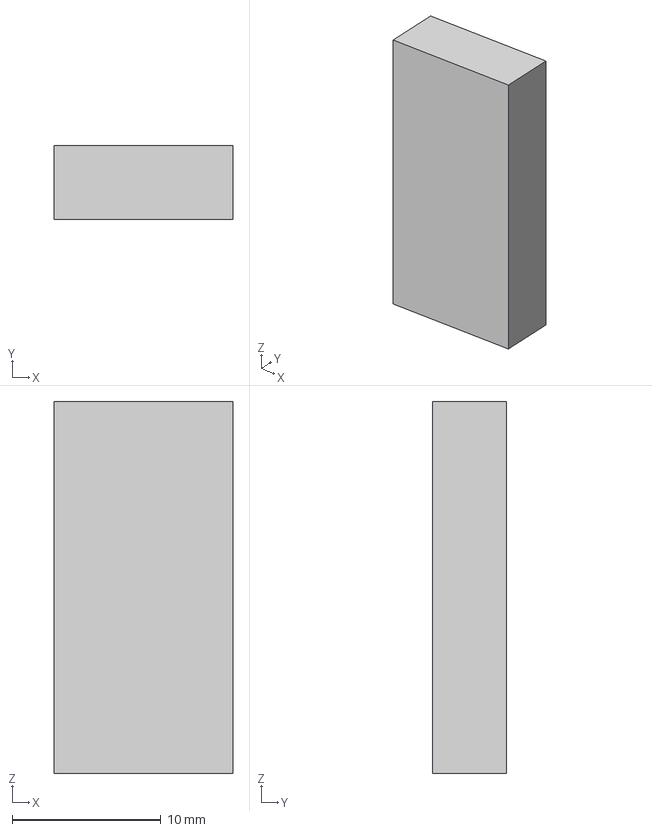
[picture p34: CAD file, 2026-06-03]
models/Mesh Hatası Eklenti.3mf
12.0 x 5.00 x 25.0 mm

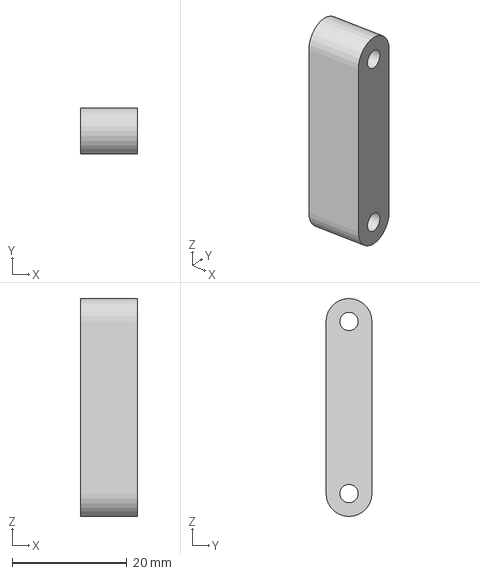
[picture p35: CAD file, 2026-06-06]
models/new_design/Wro Ana Şase_Wro Ana Şase_Kamera Tutucu Temel.3mf
10.0 x 8.00 x 38.0 mm

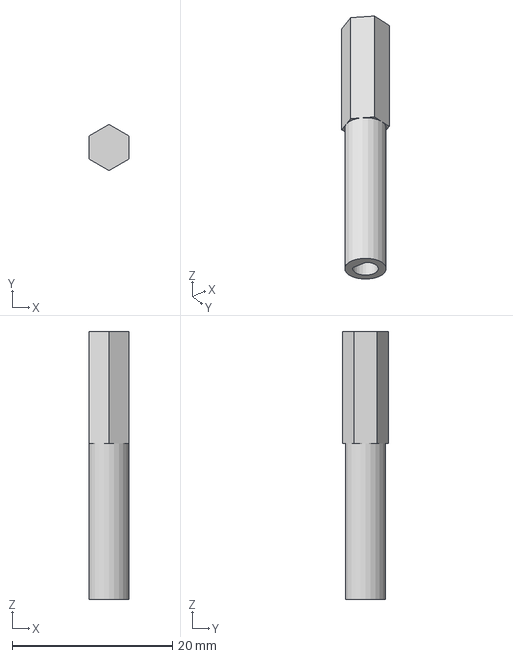
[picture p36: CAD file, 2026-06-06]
models/new_design/Wro Ana Şase_Wro Ana Şase_Arka Güç Aktarım.3mf
5.00 x 5.77 x 33.5 mm

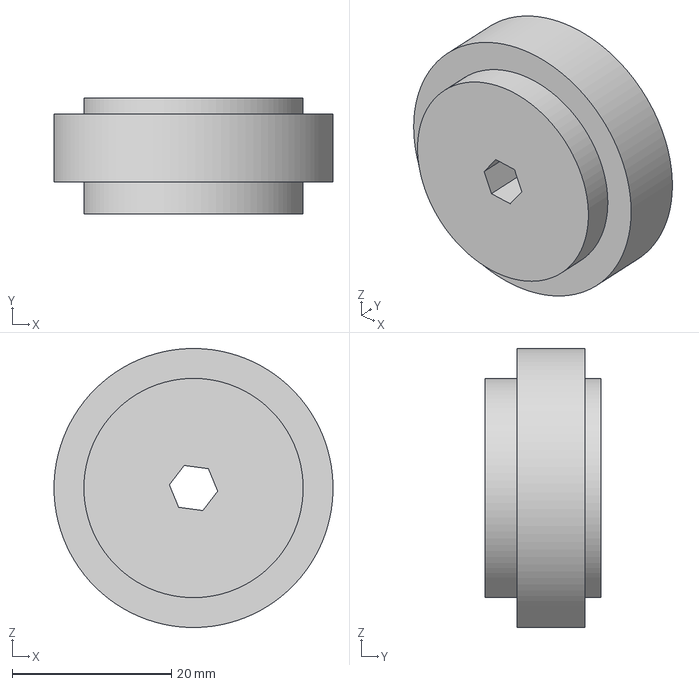
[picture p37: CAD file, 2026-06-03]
models/Tekerlek V1.5.3mf
35.0 x 14.5 x 35.0 mm

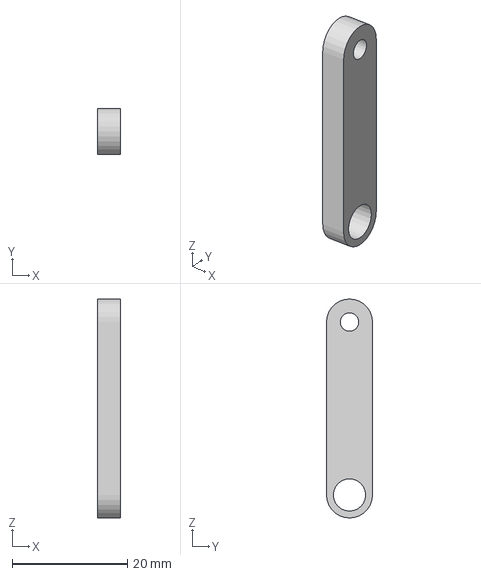
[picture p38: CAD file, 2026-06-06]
models/new_design/Wro Ana Şase_Wro Ana Şase_Kamera Tutucu Gövde.3mf
4.00 x 8.00 x 38.0 mm

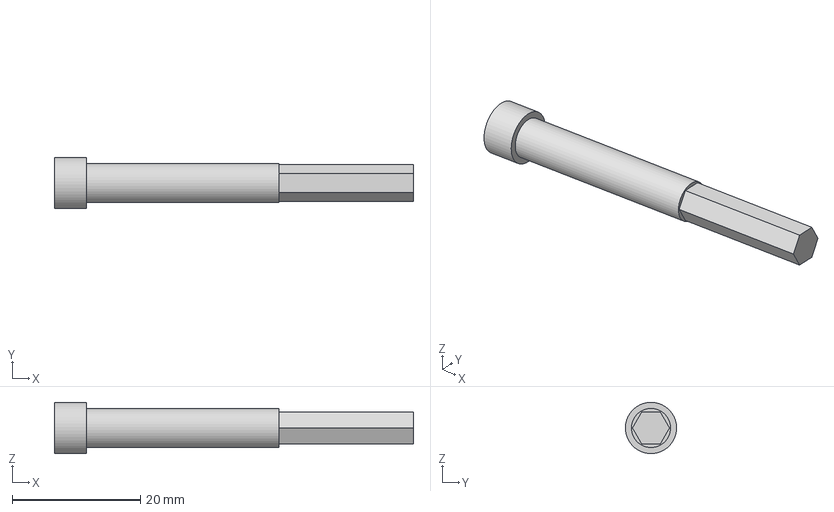
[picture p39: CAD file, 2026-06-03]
models/Ön Tekerlek Mili V1.1.3mf
56.0 x 8.00 x 7.99 mm

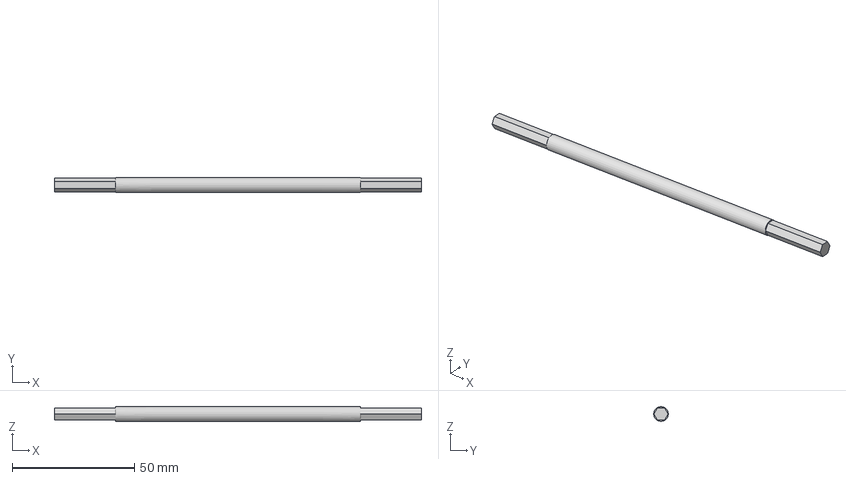
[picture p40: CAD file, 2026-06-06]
models/new_design/Wro Ana Şase_Wro Ana Şase_Arka Mil.3mf
150.0 x 6.00 x 6.00 mm

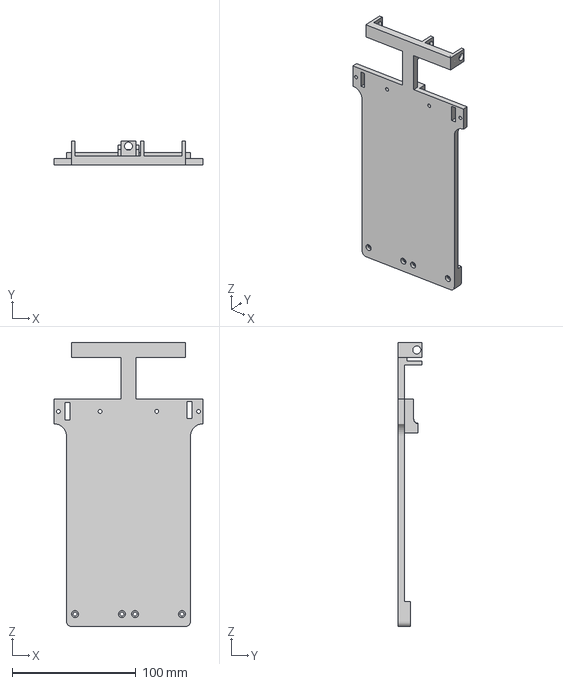
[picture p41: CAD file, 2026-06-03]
models/Gövde Ana Tam Tasarım.3mf
120.0 x 19.0 x 229.1 mm

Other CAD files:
models/new_design/Wro Ana Şase_Wro Ana Şase_6 Gen Kilit.3mf
models/Ön Mil Ackerman V1.2.3mf
models/Aks v1.2.3mf
models/new_design/Wro Ana Şase_Wro Ana Şase_Ön Tekerlek Mili.3mf
models/Aks V1.0.3mf
models/Aks V1.1.3mf
models/Arka Mil Taban V2.2.3mf
models/DGBOX P5 gear 2.3mf
models/DGBOX P5 gear V2.1.3mf
models/Direksiyon Bağlayıcı kol v1.0.3mf
models/Direksiyon Mil Ön Parça v1.0.3mf
models/Direksiyon Sol Kol v1.0.3mf
models/Dneme12.stl
models/Dİreksiyon sağ kol v11.0.3mf
models/Gövde Alt Parça.3mf
models/Gövde Ana Tam Tasarım V1.1.3mf
models/Gövde Ana Tam Tasarım V1.2.3mf
models/Gövde Arka Mil 2.1.3mf
models/Gövde Arka Mil v2.1.3mf
models/Gövde2.3mf
models/Gövde3.3mf
models/Gövde6.3mf
models/Gövde7.3mf
models/Motor Aks V1.0.3mf
models/Motor Aks V1.1.3mf
models/Tekerlek V1.0.3mf
models/Tekerlek V1.1.3mf
models/Tekerlek V1.2.3mf
models/Tekerlek V1.3.3mf
models/Tekerler V1.4.3mf
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

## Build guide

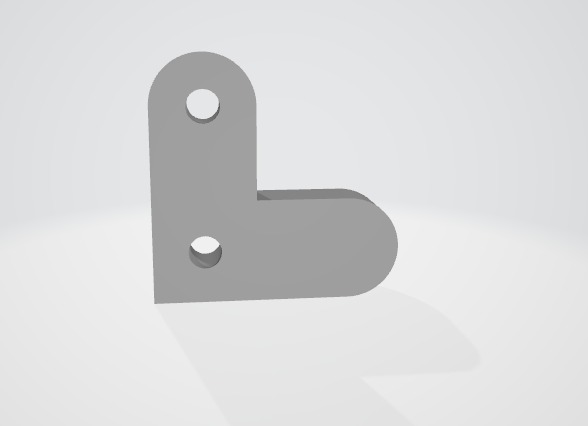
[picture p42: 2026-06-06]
models/26_baglanti_montaji.jpeg

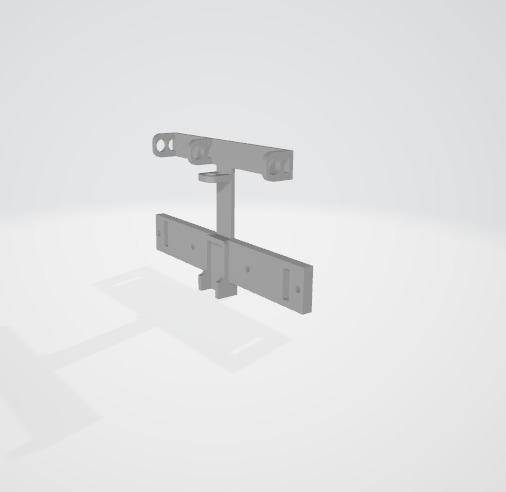
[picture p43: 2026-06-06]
models/13_direksiyon_baglayici_kol_montaji.jpeg

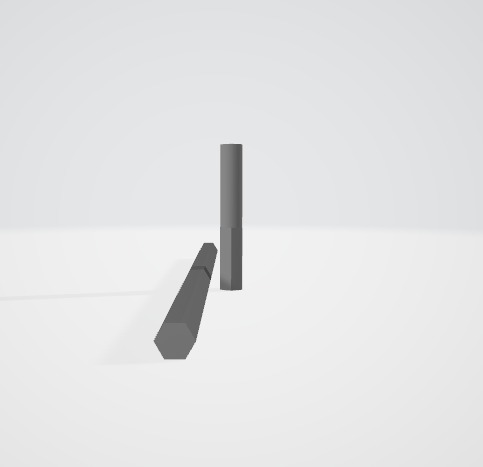
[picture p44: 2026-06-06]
models/12_aks_montaji.jpeg

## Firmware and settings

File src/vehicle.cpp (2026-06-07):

#include <Arduino.h>
#include <Wire.h>
#include <ESP32Servo.h>
#include <Adafruit_MPU6050.h>
#include <Adafruit_Sensor.h>
#include <Adafruit_GFX.h>
#include <Adafruit_SSD1306.h>

// switch control setting
const int SWITCH_ON_STATE = LOW; 
const int SWITCH_OFF_STATE = HIGH; 


const int BASE_SPEED = 150;
const int SLOW_SPEED = 100;
const int PARKING_SPEED = 80;

const float WALL_CENTER_KP = 1.5;           
const int CENTER_STEERING_ANGLE = 90;       
const int OBSTACLE_STEERING_FORCE = 35;     
const int MAX_STEER_LEFT = 45;
const int MAX_STEER_RIGHT = 135;

const int MIN_OBSTACLE_AREA = 500;          
const int SAFE_DISTANCE_CM = 15;            
const unsigned long MAX_RACE_TIME_SECONDS = 180; 

const int CORNERS_PER_LAP = 4;
const int TARGET_CORNER_COUNT = 12;         
const unsigned long MIN_TIME_BEFORE_PARKING_SEARCH = 30000; 
const int PARKING_CENTER_TOLERANCE_CM = 5;  
const unsigned long PARKING_STABLE_TIME_SECONDS = 3; 

// oled settings
const uint8_t OLED_ADDR = 0x3C;
const int SCREEN_WIDTH = 128;
const int SCREEN_HEIGHT = 64;

// pin map
#define I2C_SDA 8
#define I2C_SCL 9

#define RX_PIN 37
#define TX_PIN 36
#define SERVO_PIN 12


#define MOTOR_PWM 40
#define MOTOR_DIR1 16
#define MOTOR_DIR2 33
#define DRV8833_STBY_PIN 11 


#define START_BUTTON_PIN 1          // start switch
#define MODE_BUTTON_PIN 2           // mode switch
#define DIRECTION_BUTTON_PIN 4      // direction switch
#define GYRO_RESET_BUTTON_PIN 6     // gyro reset
#define SERVO_CENTER_BUTTON_PIN 10  // servo center
#define MOTOR_TEST_BUTTON_PIN 13    // motor test
#define UART_CHECK_BUTTON_PIN 14    // uart check
#define SENSOR_INFO_BUTTON_PIN 21   // sensor screen

// sensor pins
#define LEFT_DIST_PIN 7   
#define FRONT_DIST_PIN 5
#define RIGHT_DIST_PIN 3  
#define HALL_EFFECT_PIN 15 // hall effect input

// ============================================================================
// 4. global objects and variables
// ============================================================================
enum RaceState { WAITING_START, RUNNING, PARKING_SEARCH, PARKING, FINISHED, EMERGENCY_STOP };
enum RaceMode { OPEN_RACE, OBSTACLE_RACE };
enum RaceDirection { CLOCKWISE, COUNTER_CLOCKWISE }; 

RaceState currentState = WAITING_START;
RaceMode currentMode = OPEN_RACE;
RaceDirection currentDirection = CLOCKWISE; 

HardwareSerial PiSerial(1); 
Servo steeringServo;
Adafruit_MPU6050 mpu;
Adafruit_SSD1306 display(SCREEN_WIDTH, SCREEN_HEIGHT, &Wire, -1);

float left_distance = 0;
float right_distance = 0;
float front_distance = 0;

String pi_buffer = ""; 
String pi_steering_command = "go_straight";
String pi_speed_command = "normal_speed";
String pi_obstacle_color = "none";
String pi_obstacle_position = "none";
int pi_obstacle_area = 0;
int pi_obstacle_center_x = 0;

unsigned long race_start_time = 0;
unsigned long stable_straight_start_time = 0;
unsigned long last_pi_packet_time = 0; 
unsigned long last_display_time = 0; 
int corner_count = 0;
bool is_currently_in_corner = false;
float yaw_angle = 0;
unsigned long last_imu_time = 0;

int current_target_steering = CENTER_STEERING_ANGLE;
int current_target_speed = 0;

// ============================================================================
// 5. functions
// ============================================================================

void read_distance_sensors() {
    left_distance = analogRead(LEFT_DIST_PIN) * 0.1; 
    front_distance = analogRead(FRONT_DIST_PIN) * 0.1;
    right_distance = analogRead(RIGHT_DIST_PIN) * 0.1;
    
    if(left_distance <= 0) left_distance = 150; 
    if(right_distance <= 0) right_distance = 150;
}

void read_pi_camera_data() {
    int bytes_read = 0;
    while (PiSerial.available() && bytes_read < 30) {
        char c = PiSerial.read();
        bytes_read++;
        
        if (c == '\n') {
            pi_buffer.trim();
            int firstComma = pi_buffer.indexOf(',');
            int secComma = pi_buffer.indexOf(',', firstComma + 1);
            int thirdComma = pi_buffer.indexOf(',', secComma + 1);
            int fourthComma = pi_buffer.indexOf(',', thirdComma + 1);
            int fifthComma = pi_buffer.indexOf(',', fourthComma + 1);
            
            if (firstComma > 0 && secComma > firstComma && thirdComma > secComma && fourthComma > thirdComma && fifthComma > fourthComma) {
                pi_steering_command = pi_buffer.substring(0, firstComma);
                pi_speed_command = pi_buffer.substring(firstComma + 1, secComma);
                pi_obstacle_color = pi_buffer.substring(secComma + 1, thirdComma);
                pi_obstacle_position = pi_buffer.substring(thirdComma + 1, fourthComma);
                pi_obstacle_area = pi_buffer.substring(fourthComma + 1, fifthComma).toInt();
                pi_obstacle_center_x = pi_buffer.substring(fifthComma + 1).toInt();
                
                last_pi_packet_time = millis(); 
            }
            pi_buffer = ""; 
        } 
        else if (c != '\r') {
            pi_buffer += c; 
        }
        if (pi_buffer.length() > 80) pi_buffer = "";
    }
}

void update_imu_heading() {
    sensors_event_t a, g, temp;
    mpu.getEvent(&a, &g, &temp);
    unsigned long current_time = millis();
    float dt = (current_time - last_imu_time) / 1000.0;
    yaw_angle += (g.gyro.z * 57.2958) * dt; 
    last_imu_time = current_time;
}

int calculate_wall_centering_steering() {
    float distance_error = left_distance - right_distance;
    int steering_correction = (int)(WALL_CENTER_KP * distance_error);
    return CENTER_STEERING_ANGLE + steering_correction;
}

int calculate_obstacle_avoidance(int current_base_steering) {
    if (pi_obstacle_area < MIN_OBSTACLE_AREA) return current_base_steering;
    if (pi_obstacle_color == "red") return CENTER_STEERING_ANGLE - OBSTACLE_STEERING_FORCE;
    if (pi_obstacle_color == "green") return CENTER_STEERING_ANGLE + OBSTACLE_STEERING_FORCE;
    return current_base_steering;
}

int combine_steering_decisions() {
    int wall_steer = calculate_wall_centering_steering();
    if (currentMode == OBSTACLE_RACE) return calculate_obstacle_avoidance(wall_steer);
    return wall_steer;
}

void estimate_corner_passed() {
    bool corner_condition = false;

    if (currentDirection == COUNTER_CLOCKWISE) {
        if (yaw_angle > 75) corner_condition = true;
    } else {
        if (yaw_angle < -75) corner_condition = true;
    }

    if (corner_condition) {
        if (!is_currently_in_corner) {
            corner_count++;
            is_currently_in_corner = true;
            yaw_angle = 0; 
        }
    } else {
        if (currentDirection == COUNTER_CLOCKWISE && yaw_angle <= 20) is_currently_in_corner = false;
        if (currentDirection == CLOCKWISE && yaw_angle >= -20) is_currently_in_corner = false;
    }
}

bool detect_starting_section_again() {
    float width_difference = abs(left_distance - right_distance);
    if (width_difference < 30 && front_distance > 100) { 
        if (stable_straight_start_time == 0) stable_straight_start_time = millis();
        else if ((millis() - stable_straight_start_time) > (PARKING_STABLE_TIME_SECONDS * 1000)) return true; 
    } else {
        stable_straight_start_time = 0; 
    }
    return false;
}

// ============================================================================
// 6. SETUP
// ============================================================================

void setup() {
    Serial.begin(115200);
    PiSerial.begin(115200, SERIAL_8N1, RX_PIN, TX_PIN);
    
    // set all buttons as pullups
    pinMode(RX_PIN, INPUT_PULLUP);
    pinMode(START_BUTTON_PIN, INPUT_PULLUP);
    pinMode(MODE_BUTTON_PIN, INPUT_PULLUP);
    pinMode(DIRECTION_BUTTON_PIN, INPUT_PULLUP); 
    pinMode(GYRO_RESET_BUTTON_PIN, INPUT_PULLUP);
    pinMode(SERVO_CENTER_BUTTON_PIN, INPUT_PULLUP);
    pinMode(MOTOR_TEST_BUTTON_PIN, INPUT_PULLUP);
    pinMode(UART_CHECK_BUTTON_PIN, INPUT_PULLUP);
    pinMode(SENSOR_INFO_BUTTON_PIN, INPUT_PULLUP);
    
    pinMode(HALL_EFFECT_PIN, INPUT_PULLUP);
    
    pinMode(MOTOR_DIR1, OUTPUT);
    pinMode(MOTOR_DIR2, OUTPUT);
    pinMode(MOTOR_PWM, OUTPUT);
    pinMode(DRV8833_STBY_PIN, OUTPUT); 
    
    digitalWrite(DRV8833_STBY_PIN, LOW);
    digitalWrite(MOTOR_DIR1, LOW);
    digitalWrite(MOTOR_DIR2, LOW);
    analogWrite(MOTOR_PWM, 0);

    steeringServo.attach(SERVO_PIN);
    steeringServo.write(CENTER_STEERING_ANGLE);

    Wire.begin(I2C_SDA, I2C_SCL);
    Wire.setClock(100000); 
    mpu.begin();
    mpu.setGyroRange(MPU6050_RANGE_500_DEG);
    
    display.begin(SSD1306_SWITCHCAPVCC, OLED_ADDR);
    display.clearDisplay();
    display.setTextColor(SSD1306_WHITE);
    display.display();
}

// ============================================================================
// 7. main loop
// ============================================================================

void loop() {
    unsigned long current_time = millis();
    
    read_distance_sensors();
    read_pi_camera_data(); 
    update_imu_heading();

    // gyro reset button
    if (digitalRead(GYRO_RESET_BUTTON_PIN) == SWITCH_ON_STATE) {
        yaw_angle = 0;
    }

    // main switch check
    bool isStartSwitchOn = (digitalRead(START_BUTTON_PIN) == SWITCH_ON_STATE);

    if (!isStartSwitchOn && currentState != WAITING_START) {
        currentState = WAITING_START;
        current_target_speed = 0;
        digitalWrite(DRV8833_STBY_PIN, LOW); 
    }

    // main state machine
    switch (currentState) {
        case WAITING_START:
            current_target_speed = 0;
            current_target_steering = CENTER_STEERING_ANGLE;
            digitalWrite(DRV8833_STBY_PIN, LOW); 
            
            // direction switch
            currentDirection = (digitalRead(DIRECTION_BUTTON_PIN) == SWITCH_ON_STATE) ? COUNTER_CLOCKWISE : CLOCKWISE;
            
            // mode switch
            currentMode = (digitalRead(MODE_BUTTON_PIN) == SWITCH_ON_STATE) ? OBSTACLE_RACE : OPEN_RACE;
            
            // start switch
            if (isStartSwitchOn) {
                race_start_time = current_time;
                last_imu_time = current_time;
                corner_count = 0;
                yaw_angle = 0;
                digitalWrite(DRV8833_STBY_PIN, HIGH); 
                currentState = RUNNING;
            }
            break;

        case RUNNING:
            if (front_distance < SAFE_DISTANCE_CM) { currentState = EMERGENCY_STOP; break; }
            if ((current_time - race_start_time) > (MAX_RACE_TIME_SECONDS * 1000)) { currentState = FINISHED; break; }

            estimate_corner_passed(); 
            if (corner_count >= TARGET_CORNER_COUNT) {
                if ((current_time - race_start_time) > MIN_TIME_BEFORE_PARKING_SEARCH) currentState = PARKING_SEARCH;
            }

            current_target_steering = combine_steering_decisions();
            current_target_speed = (pi_speed_command == "slow_down" && currentMode == OBSTACLE_RACE) ? SLOW_SPEED : BASE_SPEED;
            break;

        case PARKING_SEARCH:
            current_target_steering = combine_steering_decisions();
            current_target_speed = SLOW_SPEED; 
            if (detect_starting_section_again()) currentState = PARKING;
            break;

        case PARKING:
            current_target_steering = calculate_wall_centering_steering();
            current_target_speed = PARKING_SPEED;
            if (abs(left_distance - right_distance) <= PARKING_CENTER_TOLERANCE_CM && front_distance < 40) currentState = FINISHED;
            break;

        case FINISHED:
            current_target_speed = 0;
            current_target_steering = CENTER_STEERING_ANGLE;
            digitalWrite(DRV8833_STBY_PIN, LOW); 
            break;

        case EMERGENCY_STOP:
            current_target_speed = 0;
            if (front_distance > (SAFE_DISTANCE_CM * 2)) currentState = RUNNING; 
            break;
    }

    // servo center button
    if (digitalRead(SERVO_CENTER_BUTTON_PIN) == SWITCH_ON_STATE) {
        steeringServo.write(90);
    } else {
        steeringServo.write(constrain(current_target_steering, MAX_STEER_LEFT, MAX_STEER_RIGHT));
    }
    
    // manual motor test button
    if (digitalRead(MOTOR_TEST_BUTTON_PIN) == SWITCH_ON_STATE) {
        digitalWrite(DRV8833_STBY_PIN, HIGH);
        // forward test
        digitalWrite(MOTOR_DIR1, HIGH); digitalWrite(MOTOR_DIR2, LOW); analogWrite(MOTOR_PWM, BASE_SPEED);
        delay(2000);
        // reverse test
        digitalWrite(MOTOR_DIR1, LOW); digitalWrite(MOTOR_DIR2, HIGH); analogWrite(MOTOR_PWM, BASE_SPEED);
        delay(2000);
        // stop motor
        digitalWrite(MOTOR_DIR1, LOW); digitalWrite(MOTOR_DIR2, LOW); analogWrite(MOTOR_PWM, 0);
    } 
    // normal motor output
    else {
        if (current_target_speed == 0) {
            digitalWrite(MOTOR_DIR1, LOW);
            digitalWrite(MOTOR_DIR2, LOW);
            analogWrite(MOTOR_PWM, 0);
        } else {
            digitalWrite(MOTOR_DIR1, HIGH);
            digitalWrite(MOTOR_DIR2, LOW);
            analogWrite(MOTOR_PWM, current_target_speed);
        }
    }

    // oled refresh block
    if (current_time - last_display_time >= 150) {
        display.clearDisplay();
        display.setCursor(0, 0);
        
        // uart check screen
        if (digitalRead(UART_CHECK_BUTTON_PIN) == SWITCH_ON_STATE) {
            display.setTextSize(1);
            display.println("--- UART KONTROL ---");
            display.println("");
            display.println("Pi Baglantisi:");
            
            if (last_pi_packet_time == 0 || (current_time - last_pi_packet_time > 1000)) {
                display.setTextSize(2);
                display.println("BAGLANTI");
                display.println("YOK");
            } else {
                display.setTextSize(2);
                display.println("AKTIF");
            }
        } 
        // sensor info screen
        else if (digitalRead(SENSOR_INFO_BUTTON_PIN) == SWITCH_ON_STATE) {
            display.setTextSize(1);
            display.println("--- SENSORLER ---");
            display.print("Sol IR : "); display.println(left_distance);
            display.print("Orta IR: "); display.println(front_distance);
            display.print("Sag IR : "); display.println(right_distance);
            display.print("HallEfc: "); display.println(digitalRead(HALL_EFFECT_PIN) == LOW ? "MIKNATIS VAR" : "YOK");
        }
        // normal telemetry screens
        else {
            display.setTextSize(1);
            if (currentState == WAITING_START) {
                display.println("WRO BEKLEMEDE");
                display.println("===============");
                display.print("Mod: "); display.println(currentMode == OPEN_RACE ? "OBSTACLE" : "OPEN");
                display.print("Yon: "); display.println(currentDirection == CLOCKWISE ? "SAAT YONU" : "S.Y. TERSI");
                display.println("Kontak Switch 1'i Ac!");
            } 
            else if (currentState == RUNNING) {
                display.setTextSize(2);
                display.println("YARISIYOR");
                display.setTextSize(1);
                display.print("Yon: "); display.println(currentDirection == CLOCKWISE ? "SAAT YONU" : "S.Y. TERSI");
                display.print("Tur Kosesi: "); display.print(corner_count); display.print("/"); display.println(TARGET_CORNER_COUNT);
            }
            else if (currentState == PARKING_SEARCH || currentState == PARKING) {
                display.setTextSize(2);
                display.println("PARK");
                display.println("ARANIYOR");
            }
            else if (currentState == FINISHED) {
                display.setTextSize(2);
                display.println("YARIS");
                display.println("BITTI");
                display.setTextSize(1);
                display.println("Sifirlamak Icin");
                display.println("Switch 1'i Kapat");
            }
            else if (currentState == EMERGENCY_STOP) {
                display.setTextSize(2);
                display.println("ACIL FREN");
            }
            
            // gyro data keeps updating under every normal screen
            display.setTextSize(1);
            display.print("\nGyro Acisi: ");
            display.print(yaw_angle);
        }
        
        display.display();
        last_display_time = current_time; 
    }
    
    delay(5); 
}

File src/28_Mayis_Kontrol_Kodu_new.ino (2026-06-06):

#if 1
/*
  Copyright (c) 2026 Team CENGOT

  Licensed under the MIT License. See the repository top-level LICENSE file
  for the full text.
*/
#endif

#include <Wire.h>
#include <Adafruit_MPU6050.h>
#include <Adafruit_Sensor.h>
#include <ESP32Servo.h>

// --- PIN TANIMLAMALARI ---
#define I2C_SDA 8
#define I2C_SCL 9

#define IR_SOL    3
#define IR_ORTA   5
#define IR_SAG    7

#define HIZ_SENSORU 11
#define SERVO_PIN   12

// DC Motor Sürücü Pinleri 
#define MOTOR_IN1   16
#define MOTOR_IN2   18

// --- NESNELER VE DEĞİŞKENLER ---
Adafruit_MPU6050 mpu;
Servo direksiyonServo;

// Interrupt (Kesme) değişkeni
volatile unsigned long tekerlekPulsSayisi = 0;
unsigned long oncekiZaman = 0;
const int beklemeSuresi = 100; // 100ms'de bir veri gönder

// --- KESME (INTERRUPT) FONKSİYONU ---
void IRAM_ATTR pulsSayici() {
  tekerlekPulsSayisi++;
}

void setup() {
  Serial.begin(115200);
  
  // ESP32 S2 Mini Native USB bağlantısı için KRİTİK bekleme!
  // Bilgisayarın portu tanıması için 2 saniye veriyoruz, böylece ilk verileri kaçırmayacağız.
  delay(2000); 

  Serial.println("\n--- WRO Robot Sistemi Baslatiliyor ---");

  // 1. I2C ve MPU6050 Başlatma (DÜZELTİLEN KISIM)
  Wire.begin(I2C_SDA, I2C_SCL);
  
  // Sensör adresini (0x68) ve kendi belirlediğimiz Wire hattını kütüphaneye zorunlu kılıyoruz
  if (!mpu.begin(0x68, &Wire)) {
    Serial.println("HATA: MPU6050 Bulunamadi! Kablolari kontrol edin.");
    while (1) { delay(10); } 
  }
  Serial.println("MPU6050 (Gyro/Ivme) basariyla baglandi!");
  
  // WRO için hassasiyet ayarları
  mpu.setAccelerometerRange(MPU6050_RANGE_8_G);
  mpu.setGyroRange(MPU6050_RANGE_500_DEG);
  mpu.setFilterBandwidth(MPU6050_BAND_21_HZ);

  // 2. Dijital Pin Ayarları (IR Sensörler ve Motor)
  pinMode(IR_SOL, INPUT);
  pinMode(IR_ORTA, INPUT);
  pinMode(IR_SAG, INPUT);
  pinMode(MOTOR_IN1, OUTPUT);
  pinMode(MOTOR_IN2, OUTPUT);

  // 3. Hız Sensörü Kesmesi (Interrupt)
  pinMode(HIZ_SENSORU, INPUT_PULLUP);
  attachInterrupt(digitalPinToInterrupt(HIZ_SENSORU), pulsSayici, RISING);

  // 4. Servo Motor Ayarı
  direksiyonServo.attach(SERVO_PIN, 500, 2400); 
  direksiyonServo.write(90); // Tekerlekleri başlangıçta düz konuma getir

  Serial.println("Kurulum tamamlandi. Veri akisi basliyor...\n");
  
  // Verilerin ne anlama geldiğini gösteren başlık satırı
  Serial.println("IvmeX,GyroZ,IR_Sol,IR_Orta,IR_Sag,PulsSayisi");
}

void loop() {
  unsigned long simdikiZaman = millis();

  // Her 100ms'de bir sensörleri oku ve gönder (Ana döngüyü yormamak için)
  if (simdikiZaman - oncekiZaman >= beklemeSuresi) {
    oncekiZaman = simdikiZaman;

    // --- 1. MPU6050 OKUMA ---
    sensors_event_t a, g, temp;
    mpu.getEvent(&a, &g, &temp);

    // --- 2. IR SENSÖRLERİ OKUMA ---
    int solDurum  = digitalRead(IR_SOL);
    int ortaDurum = digitalRead(IR_ORTA);
    int sagDurum  = digitalRead(IR_SAG);

    // --- 3. HIZ SENSÖRÜ OKUMA ---
    noInterrupts(); // Kesmeleri anlık durdur (veri kaybını önlemek için)
    unsigned long anlikPuls = tekerlekPulsSayisi;
    tekerlekPulsSayisi = 0; // Bir sonraki döngü için sıfırla
    interrupts(); // Kesmeleri geri aç

    // --- RASPBERRY PI İÇİN CSV FORMATINDA YAZDIRMA ---
    Serial.print(a.acceleration.x); Serial.print(",");
    Serial.print(g.gyro.z);         Serial.print(",");
    Serial.print(solDurum);         Serial.print(",");
    Serial.print(ortaDurum);        Serial.print(",");
    Serial.print(sagDurum);         Serial.print(",");
    Serial.println(anlikPuls);      
  }

  // --- RASPBERRY PI'DAN GELEN MOTOR/SERVO KOMUTLARINI DİNLEME ---
  if (Serial.available() > 0) {
    String gelenKomut = Serial.readStringUntil('\n'); 
    komutIsle(gelenKomut);
  }
}

// Raspberry Pi'den gelen komutları ayrıştıran fonksiyon
void komutIsle(String komut) {
  komut.trim();
  
  // Örn: "S:120" -> Servoyu 120 derece yap
  if (komut.startsWith("S:")) {
    int aci = komut.substring(2).toInt();
    direksiyonServo.write(aci);
  } 
  // Örn: "M:1" -> Motor ileri, "M:0" -> Motor dur
  else if (komut.startsWith("M:")) {
    int yon = komut.substring(2).toInt();
    if (yon == 1) { 
      digitalWrite(MOTOR_IN1, HIGH);
      digitalWrite(MOTOR_IN2, LOW);
    } else if (yon == 0) { 
      digitalWrite(MOTOR_IN1, LOW);
      digitalWrite(MOTOR_IN2, LOW);
    }
  }
}

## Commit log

2026-05-20 Schemes For Robot
    [Aks V1.0.3mf, Alt Gövde Main.3mf, DGBOX P5 gear 2.3mf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]
2026-06-03 Rename Aks V1.0.3mf to Scheme/Aks V1.0.3mf
    [Aks V1.0.3mf]
2026-06-03 Rename Aks V1.1.3mf to Scheme/Aks V1.1.3mf
    [Aks V1.1.3mf]
2026-06-03 Rename Alt Gövde Main.3mf to Scheme/Alt Gövde Main.3mf
    [Alt Gövde Main.3mf]
2026-06-03 Rename Arka Mil Taban V2.2.3mf to Scheme/Arka Mil Taban V2.2.3mf
    [Arka Mil Taban V2.2.3mf]
2026-06-03 Rename DGBOX P5 gear 2.3mf to Scheme/DGBOX P5 gear 2.3mf
    [DGBOX P5 gear 2.3mf]
2026-06-03 Rename DGBOX P5 gear V2.1.3mf to Scheme/DGBOX P5 gear V2.1.3mf
    [DGBOX P5 gear V2.1.3mf]
2026-06-03 Rename Direksiyon Bağlayıcı kol v1.0.3mf to Scheme/Direksiyon Bağlayıcı kol v1.0.3mf
    [Direksiyon Bağlayıcı kol v1.0.3mf]
2026-06-03 Models got carried to file
    [Direksiyon Mil Ön Parça v1.0.3mf, Direksiyon Sol Kol v1.0.3mf, Dİreksiyon sağ kol v11.0.3mf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]
2026-06-04 files has been arranged
    [Aks V1.0.3mf, Aks V1.1.3mf, Aks v1.2.3mf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]
2026-06-06 models folder rearranged, old_design and new_design is added
    [Aks V1.0.3mf, Aks V1.1.3mf, Aks v1.2.3mf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]
2026-06-06 models readme rearranged, models photos rearranged
    [models_table.csv]
2026-06-06 models folder rearranged
    [models_table.csv]
